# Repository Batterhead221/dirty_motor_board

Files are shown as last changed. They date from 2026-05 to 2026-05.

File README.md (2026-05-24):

# dirty_motor_board
DRV8461-based stepper motor driver board for Brain_Board, designed for a 17HS4412B NEMA 17 motor with SPI configuration, STEP/DIR control, VM input protection, and chunky motor-output routing.

DRV8461-based stepper motor driver daughter board for Brain_Board.

Dirty_MTR_Board handles the noisy motor-power side of the system: VM input protection, DRV8461 current-regulated stepper drive, motor output routing, and SPI/STEP-DIR control from Brain_Board.

## Overview

This board is designed for a 17HS4412B two-phase stepper motor rated for 3.9 V and 1.2 A/phase. The motor is not powered directly from 3.9 V. Instead, the DRV8461 is supplied from a higher VM rail and regulates coil current internally.

## Key Specs

| Item | Value |
|---|---|
| Driver | TI DRV8461 |
| Motor | 17HS4412B |
| Motor current | 1.2 A/phase |
| VM input | 5-24 V labeled |
| Control | STEP, DIR, EN, nSLEEP, nFAULT |
| Configuration | SPI |
| VM protection | Fuse + SMBJ26A TVS |
| VM bulk cap | 100 µF / 50 V |
| Board role | Motor driver daughter board for Brain_Board |

## Design Notes

- VM is fused and protected with an SMBJ26A TVS diode.
- VM bulk capacitance is provided by a 100 µF / 50 V radial electrolytic capacitor.
- nSLEEP has a 100 kΩ pulldown so the driver defaults to sleep.
- VREF includes a 100 nF capacitor to ground and a DNP 0 Ω option to ground.
- The DRV8461 exposed pad is tied to V-GND with thermal vias.
- Motor output traces are routed wide for 1.2 A/phase operation.

# DIRTY_MOTOR_BOARD

<p align="center">
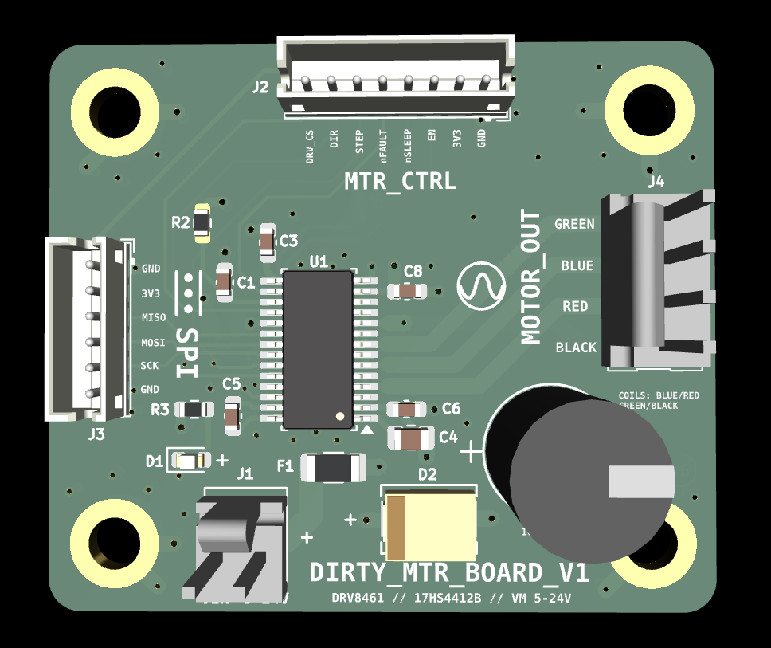
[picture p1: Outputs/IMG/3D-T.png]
DIRTY_MOTOR_BOARD top 3D board render
  
</p>

<p align="center">
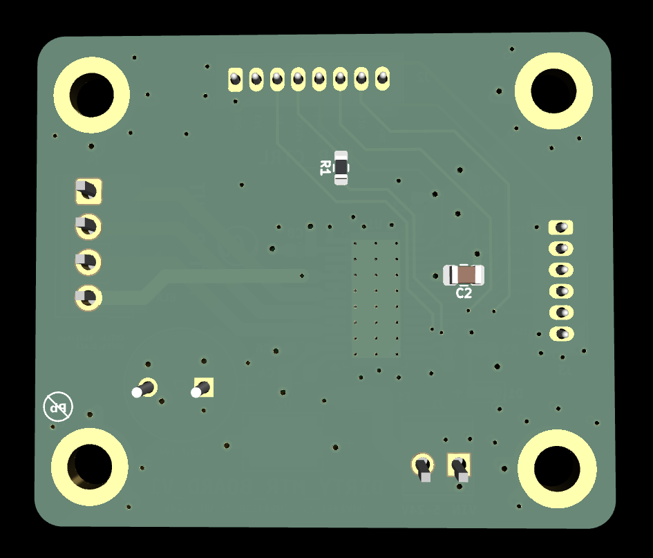
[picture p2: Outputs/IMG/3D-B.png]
DIRTY_MOTOR_BOARD bottom 3D board render
  
</p>

DRV8461-based stepper motor driver daughter board for BRAIN_BOARD, designed around a 17HS4412B NEMA 17 stepper motor with SPI configuration, STEP/DIR control, VM input protection, and high-current motor-output routing.

DIRTY_MOTOR_BOARD handles the noisy motor-power side of the system. It keeps motor current, VM protection, driver switching, and chunky output routing off the main controller board.

## Project Status

In progress / prototype hardware repository.

## System Role

```text
BRAIN_BOARD
    ↓ STEP / DIR / EN / nSLEEP / SPI / nFAULT
DIRTY_MOTOR_BOARD
    ↓ current-regulated phase outputs
17HS4412B NEMA 17 stepper motor
```

BRAIN_BOARD provides logic/control signals. DIRTY_MOTOR_BOARD handles VM power input, DRV8461 motor driving, current regulation, and motor connector routing.

## Key Specs

| Item | Value |
|---|---|
| Driver | TI DRV8461 |
| Motor target | 17HS4412B NEMA 17 stepper |
| Motor current | 1.2 A/phase |
| Motor rated voltage | 3.9 V |
| VM input label | 5-24 V |
| Control style | STEP / DIR |
| Configuration | SPI |
| Logic rail | +3.3V from controller side |
| VM protection | Fuse + SMBJ26A TVS |
| VM bulk capacitor | 100 µF / 50 V |
| Board role | Motor driver daughter board for BRAIN_BOARD |

## Important Motor Note

The 17HS4412B motor is rated for **3.9 V and 1.2 A/phase**, but the board does not simply feed the motor 3.9 V.

The DRV8461 is powered from the VM rail and regulates motor coil current internally. The motor voltage rating is not the same thing as the VM supply voltage for a current-regulated stepper driver.

## Main Features

- DRV8461 stepper motor driver
- STEP/DIR control interface
- SPI configuration interface
- EN, nSLEEP, and nFAULT control/status signals
- VM input fuse/protection path
- SMBJ26A TVS diode on VM
- 100 µF / 50 V VM bulk capacitor
- Wide motor-output routing
- Exposed-pad thermal via strategy
- Motor connector matched to measured coil pairs
- Daughter-board connection to BRAIN_BOARD

## Connectors

### J1 - VM Power Input

| Pin | Signal |
|---:|---|
| 1 | GND |
| 2 | VIN / VM |

J1 brings in the motor power supply rail.

```text
VM input → fuse/protection → VM bulk capacitance → DRV8461 VM
```

### J2 - Motor Control

| Pin | Signal |
|---:|---|
| 1 | GND |
| 2 | +3V3 |
| 3 | EN |
| 4 | nSLEEP |
| 5 | nFAULT |
| 6 | STEP |
| 7 | DIR |
| 8 | DRV_CS |

J2 carries the main logic/control signals between BRAIN_BOARD and DIRTY_MOTOR_BOARD.

### J3 - SPI

| Pin | Signal |
|---:|---|
| 1 | GND |
| 2 | +3V3 |
| 3 | SPI_MISO |
| 4 | SPI_MOSI |
| 5 | SPI_SCK |
| 6 | GND |

J3 carries the SPI bus used for DRV8461 configuration/status access.

### M1 - Motor Output

| Pin | Signal |
|---:|---|
| 1 | AOUT2 |
| 2 | BOUT1 |
| 3 | BOUT2 |
| 4 | AOUT1 |

Measured motor coil pairs:

| Coil | Motor connector pins |
|---|---|
| Coil A | pins 1 and 4 |
| Coil B | pins 2 and 3 |

## DRV8461 Control Signals

| Signal | Direction | Purpose |
|---|---|---|
| STEP | Controller → driver | Step pulse input |
| DIR | Controller → driver | Direction input |
| EN | Controller → driver | Driver enable control |
| nSLEEP | Controller → driver | Sleep/wake control |
| nFAULT | Driver → controller | Fault/status output |
| DRV_CS | Controller → driver | SPI chip select |
| SPI_MISO | Driver → controller | SPI data back to controller |
| SPI_MOSI | Controller → driver | SPI data to driver |
| SPI_SCK | Controller → driver | SPI clock |

## Power Architecture

```text
VM input
    ↓
fuse/protection
    ↓
SMBJ26A TVS clamp to GND
    ↓
100 µF / 50 V bulk capacitor
    ↓
DRV8461 VM pins
    ↓
AOUT/BOUT motor phase outputs
```

Logic power comes from the controller side:

```text
BRAIN_BOARD +3.3V → DIRTY_MOTOR_BOARD logic/interface rail
```

## Design Notes

- VM is fused and protected with an SMBJ26A TVS diode.
- VM bulk capacitance is provided by a 100 µF / 50 V radial electrolytic capacitor.
- nSLEEP has a 100 kΩ pulldown so the driver defaults to sleep.
- VREF includes a 100 nF capacitor to ground and a DNP 0 Ω option to ground.
- The DRV8461 exposed pad is tied to V-GND with thermal vias.
- Motor output traces are routed wide for 1.2 A/phase operation.
- Keep motor-output routing away from sensitive logic/control traces where practical.
- Keep VM bulk capacitance close to the driver power path.
- The board is intentionally separated from BRAIN_BOARD to keep noisy motor current off the main controller PCB.

## Bring-Up Checklist

1. Inspect DRV8461 soldering, exposed pad, and thermal vias.
2. Check for shorts between VM and GND before applying power.
3. Check for shorts between +3.3V and GND.
4. Power logic side first if possible and confirm +3.3V.
5. Confirm nSLEEP default behavior before enabling the driver.
6. Apply VM current-limited during first power-up.
7. Confirm SPI communication with the DRV8461.
8. Confirm nFAULT is not asserted.
9. Connect motor and verify coil-pair order.
10. Start with low current/settings before full 1.2 A/phase operation.

## Repository Output Images

Expected image paths for GitHub README rendering:

```text
Outputs/
  IMG/
    3D-T.png
    3D-B.png
    SCHEMATIC.png
    L1-SIG.png
    L2-3V3.png
    L3-GND.png
    L4-MIX.png
```

## Safety / Design Note

DIRTY_MOTOR_BOARD handles higher-current motor power. Verify VM polarity, current limit, motor wiring, driver configuration, thermal behavior, and fuse/protection choices before running a motor under load.

Designed & engineered by Brandon Shelly.

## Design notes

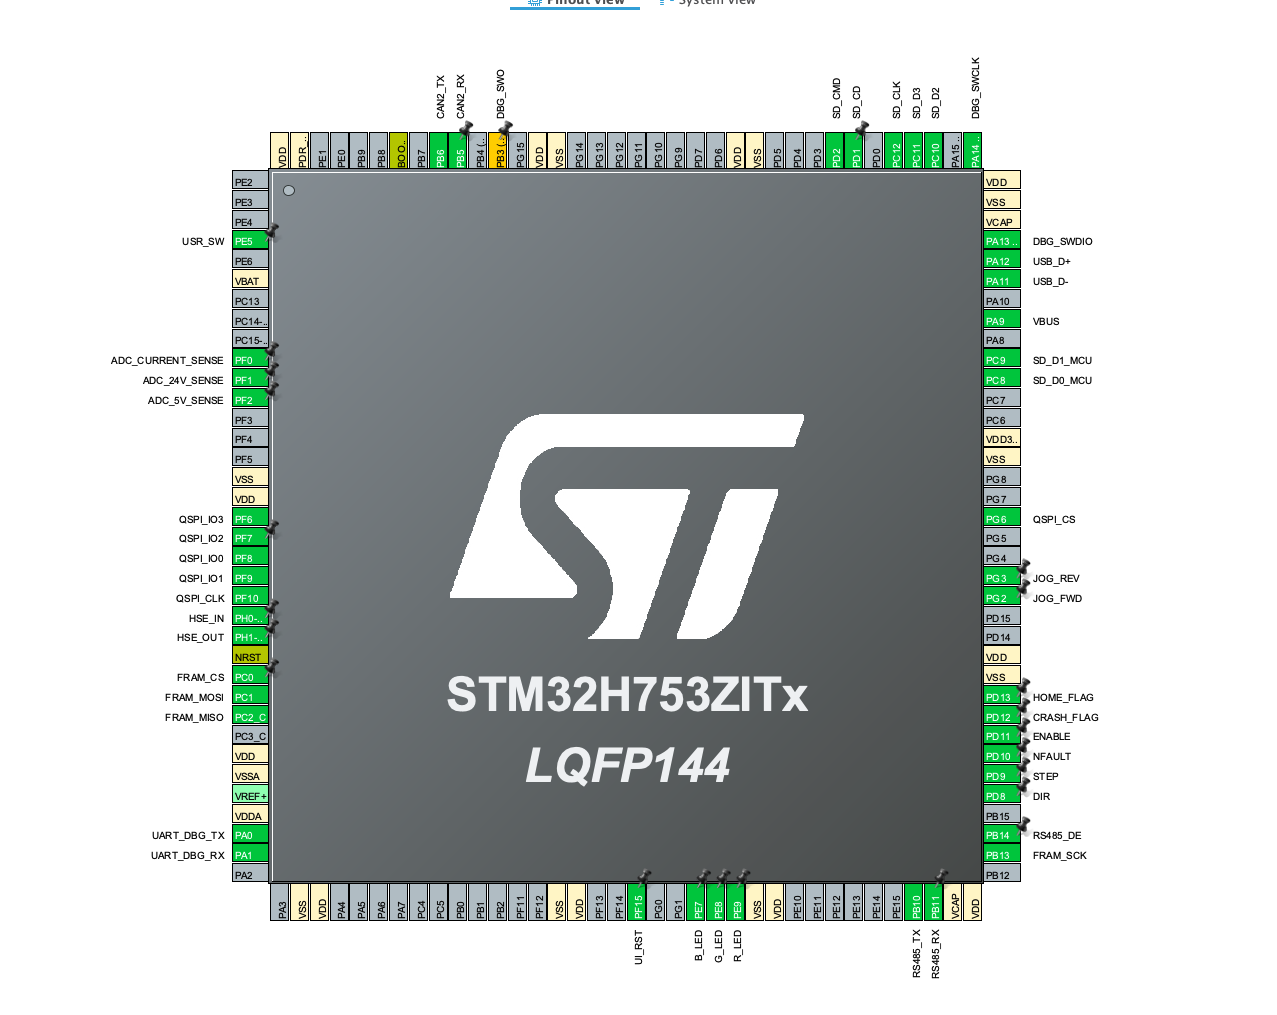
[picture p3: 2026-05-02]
docs/STM32.png

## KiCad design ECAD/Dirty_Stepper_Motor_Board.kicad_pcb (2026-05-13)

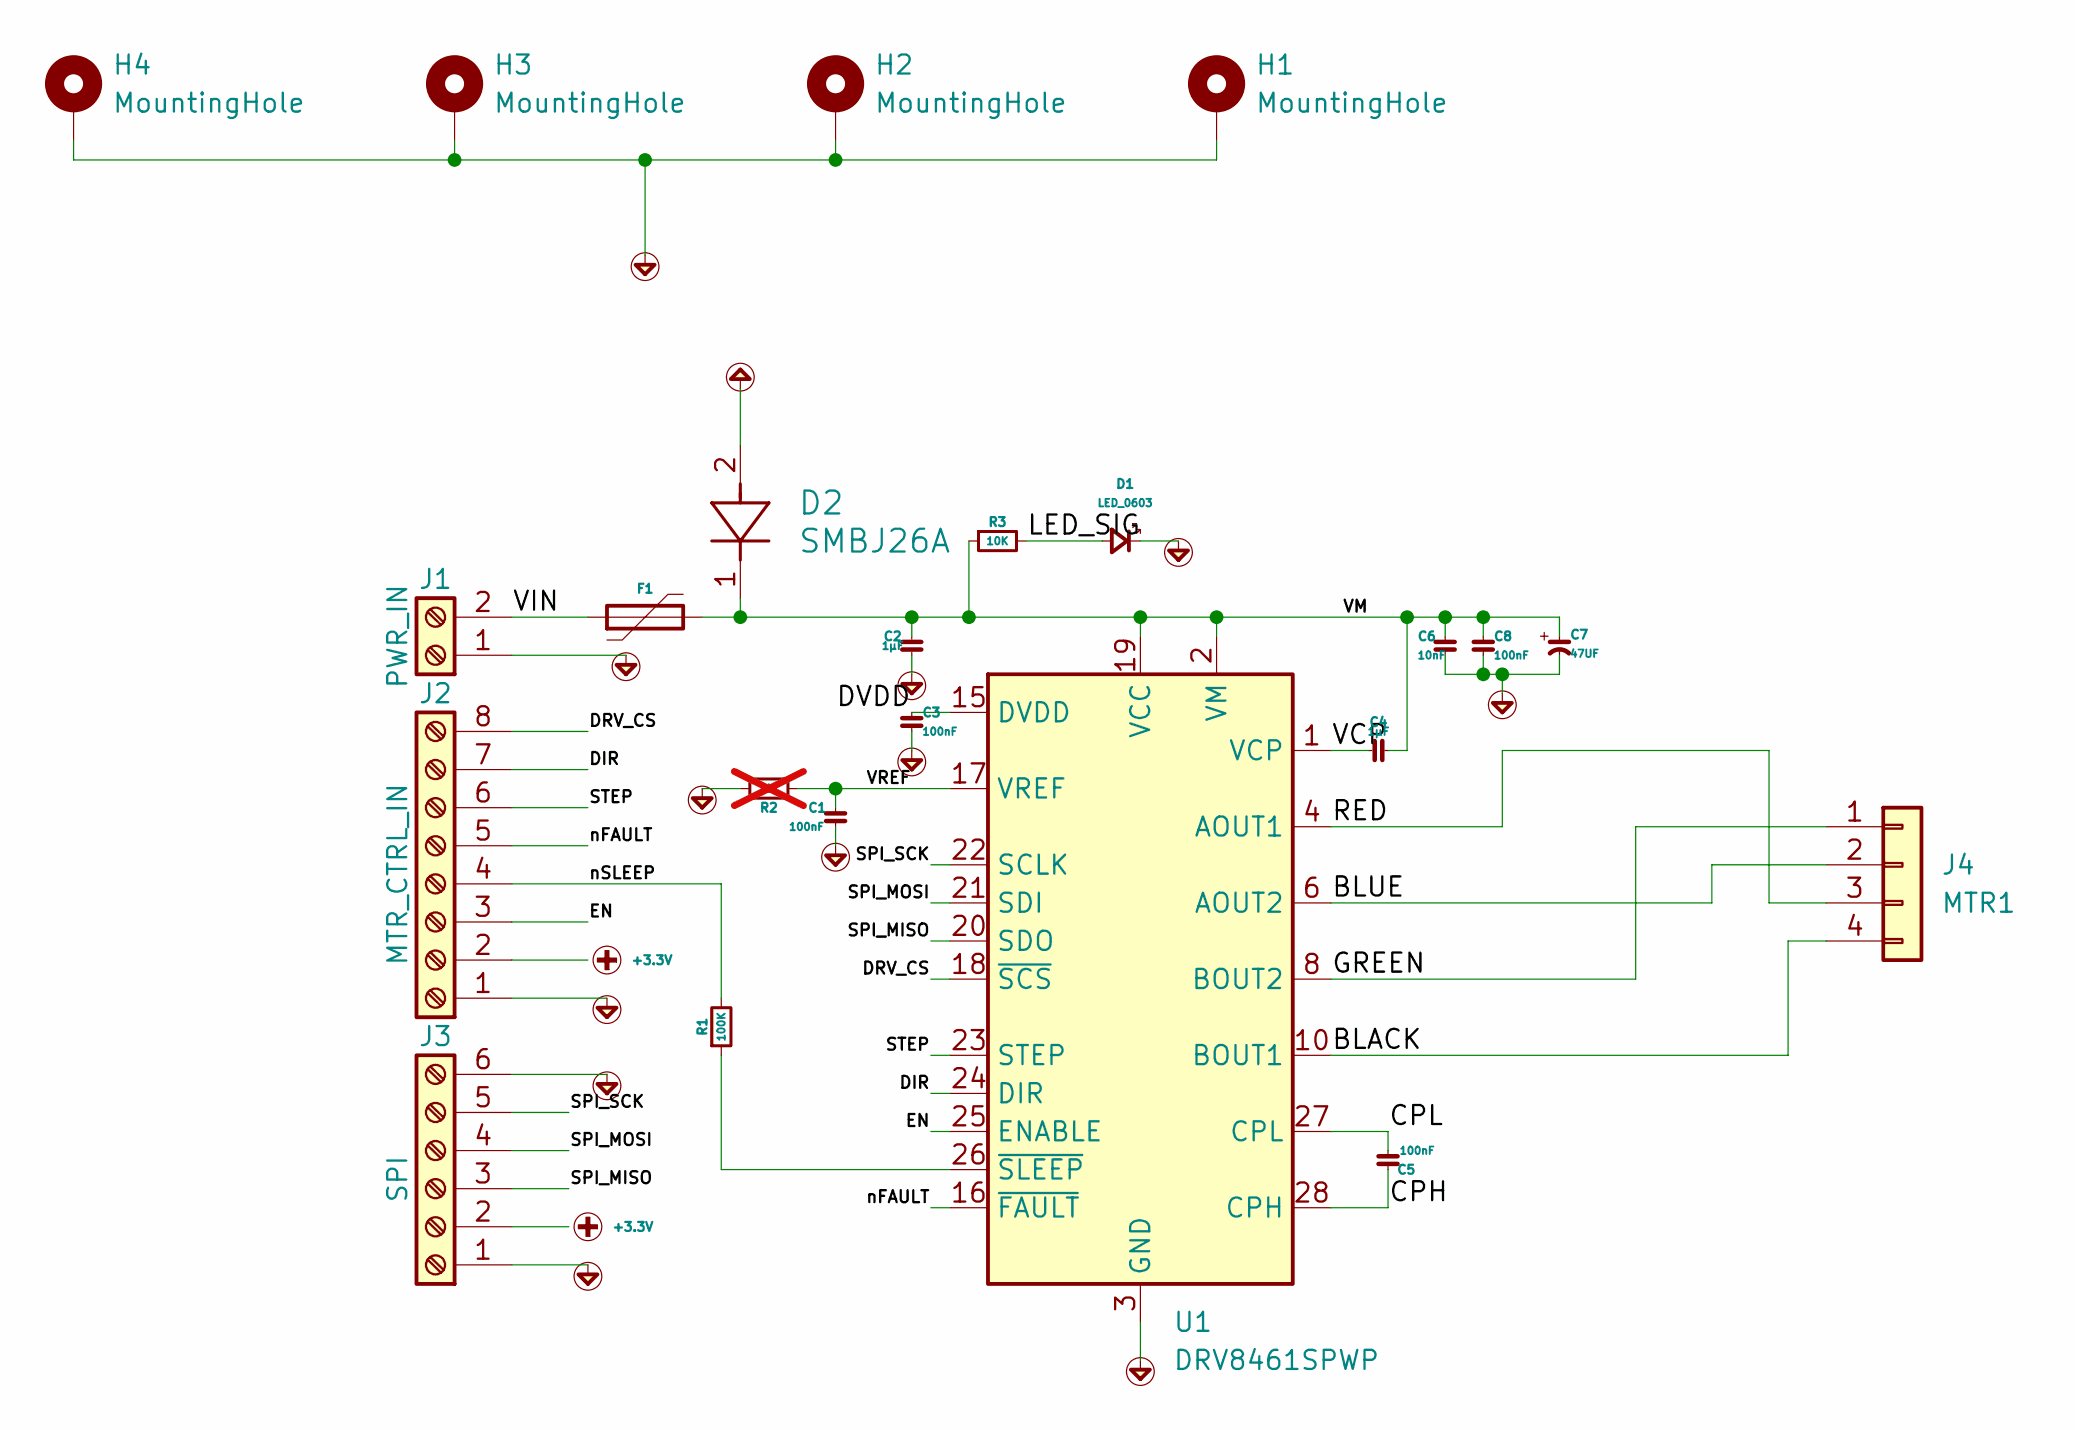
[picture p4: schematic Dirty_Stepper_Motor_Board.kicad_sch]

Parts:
C1, C3, C5, C8: 100nF; C_0603_1608Metric
C2, C4: 1µF; C_0805_2012Metric; MPN C3216X5R1V226M160AC
C6: 10nF; C_0603_1608Metric
C7: 47UF; PCAP_8x11_5-THRU-ELECT_NCA
D1: LED_0603; LED_0603_1608Metric
D2: SMBJ26A; SMBJSeries_LTF
F1: Polyfuse; Fuse_1206_3216Metric
H1, H2, H3, H4: MountingHole; MountingHole_3.2mm_M3_ISO14580_Pad
J1: PWR_IN; TE_3-641126-2
J2: MTR_CTRL_IN; JST_EH_B8B-EH-A_1x08_P2.50mm_Vertical
J3: SPI; JST_EH_B6B-EH-A_1x06_P2.50mm_Vertical
J4: MTR1; MTA-4
R1: 100K; R_0603_1608Metric
R2: 0; R_0603_1608Metric; not fitted
R3: 10K; R_0603_1608Metric
U1: DRV8461SPWP; Texas_PWP0028V_TSSOP-28-1EP_4.4x9.7mm_P0.65mm_EP3.4x9.7mm_M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

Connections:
+3.3V: J2.2, J3.2
/BLACK: J4.4, U1.10 (BOUT1), U1.11 (BOUT1)
/BLUE: J4.2, U1.6 (AOUT2), U1.7 (AOUT2)
/CPH: C5.2, U1.28 (CPH)
/CPL: C5.1, U1.27 (CPL)
/DIR: J2.7, U1.24 (DIR)
/DRV_CS: J2.8, U1.18 (~SCS)
/DVDD: C3.2, U1.15 (DVDD)
/EN: J2.3, U1.25 (ENABLE)
/GREEN: J4.1, U1.8 (BOUT2), U1.9 (BOUT2)
/LED_SIG: D1.2 (A), R3.2
/RED: J4.3, U1.4 (AOUT1), U1.5 (AOUT1)
/SPI_MISO: J3.3, U1.20 (SDO)
/SPI_MOSI: J3.4, U1.21 (SDI)
/SPI_SCK: J3.5, U1.22 (SCLK)
/STEP: J2.6, U1.23 (STEP)
/VCP: C4.1, U1.1 (VCP)
/VIN: F1.1, J1.2
/VM: C2.2, C4.2, C6.2, C7.1, C8.2, D2.1, F1.2, R3.1, U1.2 (VM), U1.13 (VM), U1.19 (VCC)
/VREF: C1.2, R2.1, U1.17 (VREF)
/nFAULT: J2.5, U1.16 (~FAULT)
/nSLEEP: J2.4, R1.2
unnamed: R1.1, U1.26 (~SLEEP)
V-GND: C1.1, C2.1, C3.1, C6.1, C7.2, C8.1, D1.1 (K), D2.2, H1.1 (1_1), H2.1 (1_1), H3.1 (1_1), H4.1 (1_1), J1.1, J2.1, J3.1, J3.6, R2.2, U1.3 (GND), U1.12 (GND), U1.14 (GND), U1.29 (GND)

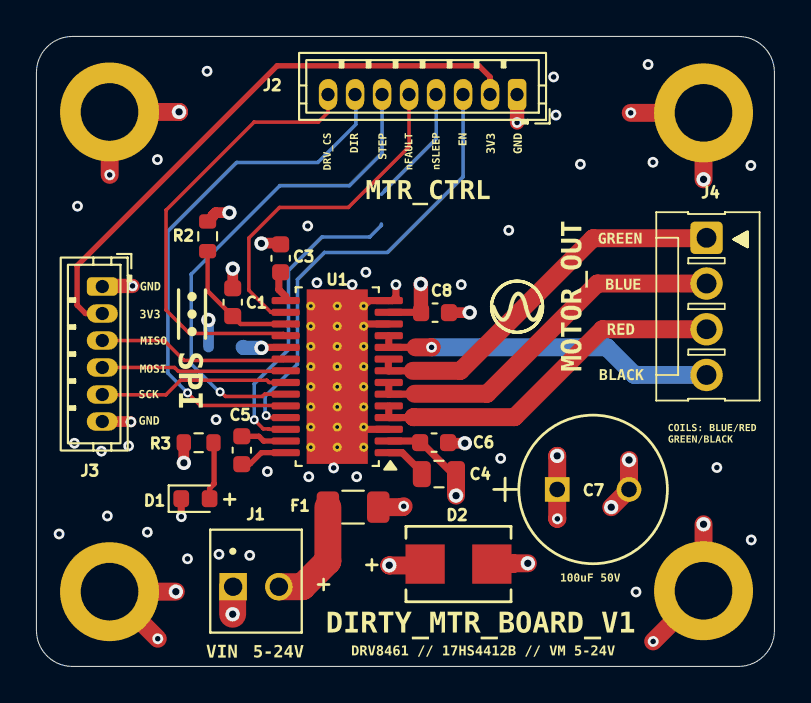
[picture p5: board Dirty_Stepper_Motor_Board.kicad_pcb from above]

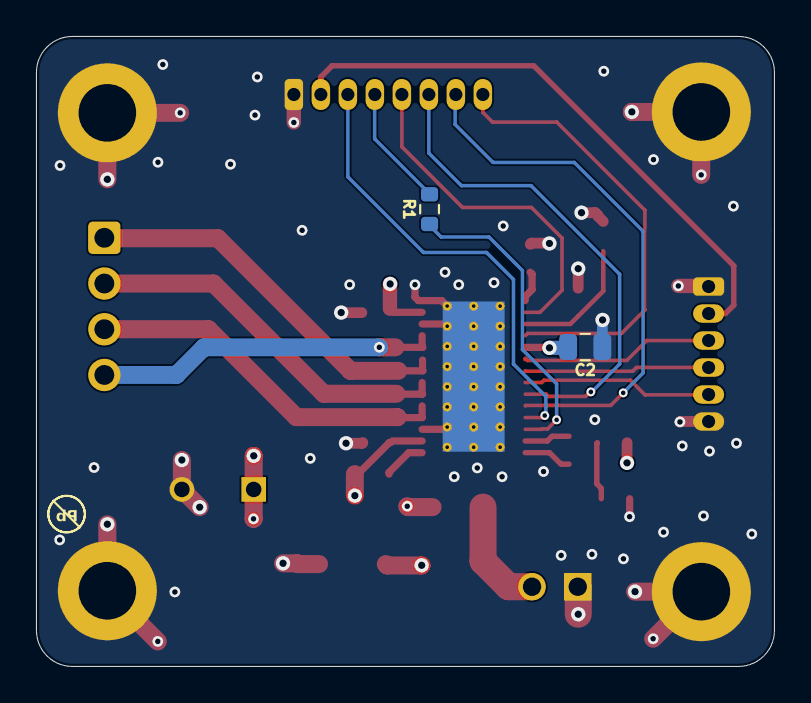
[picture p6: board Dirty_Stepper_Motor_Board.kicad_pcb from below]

Board: 4 copper layers, 41.0 x 35.0 mm, 23 parts (2 on the bottom side), 24 nets.

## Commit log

2026-05-03 folder restructure
    [Dirty_Stepper_Motor_Board.kicad_pcb, Dirty_Stepper_Motor_Board.kicad_sch]
2026-05-13 Revised repo
    [Dirty_Stepper_Motor_Board.kicad_pcb, Dirty_Stepper_Motor_Board.kicad_sch]
2026-05-13 Added stitching vias
    [Dirty_Stepper_Motor_Board.kicad_pcb, Dirty_Stepper_Motor_Board.kicad_sch]
